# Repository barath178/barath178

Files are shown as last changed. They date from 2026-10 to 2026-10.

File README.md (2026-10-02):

<h1 align="center">Hi, I'm barath178 👋</h1>
<p align="center"><i>Building data-driven tools for agriculture, energy and hardware, from physics models to live dashboards.</i></p>

<p align="center">
  
  
  
  
  
  
</p>

## 🚀 Featured projects

### 🌾 [AeroAgro AI: Panchayat-level weather downscaling](https://github.com/barath178/panchayat-weather-downscaling)
Turns 12–25 km forecasts into ~1.2 km village-level weather using terrain physics (lapse rate, cold-air drainage, orographic lift), then converts it into farmer advisories: spraying, irrigation, pest alerts and PMFBY crop-insurance evidence.
`TypeScript` · [Live site](https://aeroagro.vercel.app)

### 🛢️ [Baghewala CSS + SRP Digital Twin (SIH26120)](https://github.com/barath178/sih26120-digital-twin)
A well-to-surface digital twin for heavy-oil wells that couples Cyclic Steam Stimulation with sucker-rod pumps and searches both settings together. Engineers approve every change. Built on synthetic data, with 92 tests.
`Python` · `React` · `Docker` · [Live demo](https://sih26120-digital-twin-lilac.vercel.app)

### 💪 EMG Gesture Classifier *(private)*
Real-time hand-gesture recognition: BioAmp EXG Pill → Arduino (500 Hz) → filtering → feature extraction → Random Forest / SVM.
`Python` · `Arduino`

## 📊 GitHub stats

<p align="center">
  
  
</p>
<p align="center">
  
</p>

## 📫 Connect
Find my work at [github.com/barath178](https://github.com/barath178).

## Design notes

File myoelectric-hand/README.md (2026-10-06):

# Myoelectric prosthetic hand: complete parts set

This is a rebuild of `original/myoelectric hand buy.step` with every part in place.

The original STEP file held 5 components, and most of them were bare surfaces with no thickness: one finger, the thumb, one side plate, one tab and the wrist puck. The screenshots in `original/` show the full design: 4 sheet-metal fingers (钣金手指), a removable thumb (可拆卸拇指), an emergency-release pin (紧急释放开关), a motor (发动机), two side plates and a base bracket. This folder rebuilds the full design as solid, printable parts. They are built around the exact geometry of the original components.

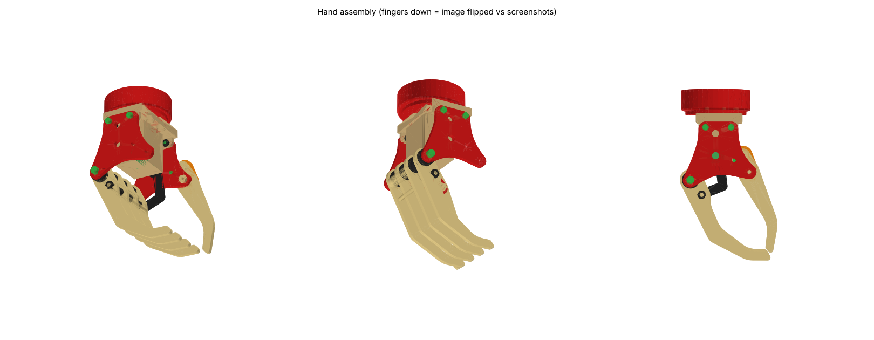
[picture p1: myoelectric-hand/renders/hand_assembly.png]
hand

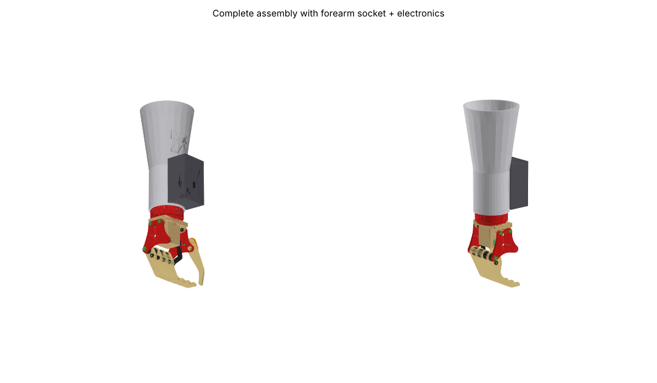
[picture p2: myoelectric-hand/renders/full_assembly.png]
full


## What is where

| Path | Contents |
|---|---|
| `solidworks/` | **For SolidWorks 2025:** 35 part STEP files, an instanced assembly STEP, and a macro that creates .SLDPRT and .SLDASM files. See `solidworks/README.md`. |
| `cad/myoelectric_hand_complete.step` | Full assembly (60 parts, coloured, named). Open it in Fusion, SolidWorks or FreeCAD. |
| `stl_print_ready/` | **Files to slice.** One STL per unique printed part, already laid flat. The quantity is in the file name (`finger_x4.stl` means print 4). |
| `cad/parts_print_step_stl/` | Each printed part as STEP and STL, in assembly position. Use these for editing. |
| `cad/parts_hardware_reference/` | Bought parts (motor, screws, pins, electronics), for fit-checking only. **Do not print.** |
| `cad/print_list.json`, `cad/manifest.json` | Part sizes, volumes and validity flags. |
| `source/` | The CadQuery script that generates everything (`build.py`) and the checks (`check.py`, `motion.py`, `verify_orig.py`). |
| `original/` | Your original STEP file and screenshots, unchanged. |

Units are mm. In assembly coordinates, +Z points toward the forearm, so the fingers hang toward −Z. This is upside down compared with the screenshots. The hand is symmetric about the plane y = −23, which is the wrist axis.

## Which dimensions came from your file, and which are new

**Taken exactly from your STEP file (verified with a 0.000 mm difference):**
- **Finger** (Component75): the full outline, the Ø8 pivot hole at (−17.64, −17.15) and the Ø3 hole at (−9.87, −27.70). The plate is 3.0 mm thick, which the file shows directly through its 0.5 mm edge fillets.
- **Thumb** (Component77): the full outline and both Ø8 holes, at (23.87, −11.50) and (19.97, 0.97).
- **Side plate** (Component78): the full outline and all six holes. These are Ø2.9 at the finger pivot, the thumb pivot and the two tab screws, and Ø5.2 at (0, 0) and (0, 15.6).
- **Tab** (Component76): the outline and its two Ø2.7 holes. It is now part of the base bracket.
- **Wrist puck** (Component79): Ø50 × 14.7 mm with a 1.5 mm fillet, a Ø44 × 2.6 mm spigot, a Ø18.2 bore and a Ø1.5 hole.

**Assumed, because your file has no thickness information for these parts:**
- The side plate, tab and thumb are 3.0 mm thick, the same as the finger.
- The second side plate is a mirror of the first about y = −23. With four fingers spaced 13.33 mm apart, the spacing and the 3 mm side gaps come out equal.
- The thumb sits outside the front plate, between the plate and the orange rocker, as in your screenshots. In the STEP file it sat 10 mm further in, where it would hit finger 1.

**Designed new, to fit the original holes:**
- the base bracket and motor housing
- the pivot tube and spacers
- the coupling-rod spacers
- the crank and the dog-leg drive link
- the thumb rocker
- the forearm socket
- the electronics enclosure and lid

The forearm socket is a generic cone, Ø55 at the wrist and Ø84 at the top, 163 mm long. **It has to be re-shaped to fit the user's own limb before it is worn.**

## Holes added to original parts

Only two holes were added, and none was removed or moved:
- the side plate gets a Ø3.2 hole at (13, −3) for the release pin
- the wrist puck gets M3 pilot holes for the base and socket screws

## Read this before you print

1. **The original Ø2.9 holes are smaller than an M3 screw (3.0 mm).** These are the side-plate finger pivot, the thumb pivot and the tab-screw holes. I kept your size. After printing, drill them to Ø3.2 if you want a clearance fit, or leave them at Ø2.9 so the M3 screw self-taps.
2. On new holes I added 0.2 mm of radial clearance. On a well-calibrated printer, holes still print about 0.1–0.2 mm small. Run a reamer or drill bit through the pivot holes so the fingers swing freely.
3. Suggested settings are PETG or PLA+, 0.2 mm layers, 4 walls and 40 % infill. Print the fingers, side plates, thumb, rocker, crank and link at 100 % infill. The pivot tube is better made from an Ø8 aluminium rod, drilled and tapped M3 at both ends.
4. The STLs in `stl_print_ready/` are already oriented for printing. The base bracket prints with its top face on the bed, and the motor pocket bridges 12 mm. The enclosure prints with its open side down. The socket prints standing up.

## Parts list

**Printed parts** (`stl_print_ready/`):

| File | Qty | Note |
|---|---|---|
| finger_x4 | 4 | original outline |
| side_plate_x2 | 2 | original outline. Print 2 and flip one. |
| thumb_x1 | 1 | original outline |
| thumb_rocker_x1 | 1 | orange rocker; holds the thumb, pivot and release pin |
| base_bracket_with_motor_housing_x1 | 1 | the original tab mirrored on both sides, the base plate and the N20 housing |
| wrist_puck_x1 | 1 | original |
| finger_pivot_tube_x1 | 1 | or an Ø8 aluminium rod |
| pivot_spacer_between_fingers_x3, pivot_spacer_front_x1, pivot_spacer_back_x1 | 5 | |
| rod_spacer_x3 | 3 | |
| crank_arm_x1, drive_link_x1 | 1 each | |
| forearm_socket_x1 | 1 | adapt to the user |
| electronics_enclosure_x1, enclosure_lid_x1 | 1 each | |

**Hardware to buy:**

| Item | Qty | Where it goes |
|---|---|---|
| N20 gear motor, 6 V, about 50 rpm (1:298), Ø3 D-shaft × 10 mm | 1 | motor housing, coaxial with the plate hole at (0, 0) |
| M1.6 × 4 screws | 2 | motor face |
| M3 threaded rod, 52 mm | 1 | finger coupling rod, through the Ø3 hole in every finger |
| M3 nuts | 3 | 2 on the coupling rod, 1 on the thumb pivot |
| M3 × 8 socket-head screws | 6 | 2 hold the pivot tube to the plates, 4 hold the base to the puck |
| M3 × 10 socket-head screws | 3 | socket to puck |
| M3 × 14 screw | 1 | thumb pivot |
| M2.5 × 8 screws and nuts | 4 + 4 | tab to side plates |
| M2.5 × 8 screws | 4 | enclosure lid |
| Ø3 steel pin, cut to 3.6 mm | 1 | crank pin |
| Ø3 × 12 pull pin with head | 1 | emergency release (紧急释放开关) |
| Ø8 × 6 pin with a Ø10 head | 1 | thumb to rocker |
| MyoWare 2.0 EMG sensor and electrodes | 1 | pocket inside the socket |
| Arduino Nano, DRV8833 motor driver | 1 each | enclosure |
| 2S LiPo battery, about 50 × 30 × 10 mm, with a switch | 1 | enclosure. Limit the motor PWM to 80 % or less, because the N20 is rated 6 V. |

## How the hand moves

- **Fingers:** all four fingers turn on the Ø8 pivot tube. The M3 coupling rod and spacers lock them together.
- **Drive:** the N20 motor turns a 5 mm crank. A 34.4 mm dog-leg link joins the crank to the coupling rod at finger 1.
- **Range of motion:** one crank turn takes the fingers from your STEP pose (closed, tips touching the thumb) to 91° open and back.
- **Grip lock:** in the closed pose the crank is at dead-centre, so the grip holds without motor power.
- **Thumb:** the thumb is passive. It is pinned to the rocker, and the rocker pivots on the front plate. Pull the release pin and the thumb swings free.

## Checks run (all scripts in `source/`)

- All 60 parts are valid single solids, and all printed STLs are watertight.
- No parts overlap. The only overlaps are screws biting into their pilot holes, which is intended.
- **Motion check:** the drive was turned through a full crank revolution in 10° steps, moving the fingers, coupling rod, link and crank each time. Nothing collided at any step.
- Every original outline and hole was compared with your STEP file: the difference is 0.000 mm.

## Not tested

- Nothing has been printed. Check the fit of the first finger, side plate and pivot tube before printing the full set.
- The forearm socket is a placeholder shape. It needs fitting to the user's limb.
- Grip force depends on which N20 gear ratio you buy. A 1:298 ratio gives roughly 10–15 N at the fingertip.
- The EMG firmware isn't included.

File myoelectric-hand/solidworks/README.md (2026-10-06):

# SolidWorks 2025 package

SolidWorks .SLDPRT and .SLDASM files can only be written by SolidWorks itself. This folder has everything needed to create them on your PC. Choose **one** of the two methods below. Both give you native part files and an assembly file.

| File | What it is |
|---|---|
| `parts/*.step` | 35 part files, one per unique part (mm, AP214, with colours). Printed parts have plain names; bought parts start with `HW`. |
| `Myoelectric Hand Assembly.step` | The full assembly: 60 components that reference those 35 parts. The 4 fingers are one part used 4 times. |
| `instances.csv` | Position and orientation of each of the 60 components. The macro reads it. |
| `BuildSolidWorksAssembly.bas` | SolidWorks VBA macro for method B. |

## Method A: open the assembly STEP (no macro)

1. In SolidWorks 2025, go to **File → Open** and set the file type to *STEP AP203/214/242 (\*.step;\*.stp)*. Click **Options…** and make sure *Import multiple bodies as parts* is selected, so the file opens as an assembly.
2. Open `Myoelectric Hand Assembly.step`. If you're asked whether to run Import Diagnostics, answer **No**.
3. Go to **File → Save As → Assembly (\*.sldasm)**. When asked about the components, choose **Save all as external files** (or *Save internally* if you prefer a single file). This gives you `Myoelectric Hand Assembly.SLDASM` and 35 `.SLDPRT` files.

## Method B: run the macro (one .SLDPRT per STEP, plus an assembly with every component fixed in place)

1. Go to **Tools → Macro → New…** and save an empty macro, for example `hand.swp`.
2. In the VBA editor that opens, choose **File → Import File…** and select `BuildSolidWorksAssembly.bas`. Then run **Main** (F5).
3. When the folder picker appears, select **this `solidworks` folder**.
4. The macro converts the 35 STEP files into `native_sldworks\*.SLDPRT`. It then builds `native_sldworks\Myoelectric Hand Assembly.SLDASM`, placing all 60 components and fixing each one.

## Notes

- All parts share one coordinate system, and each part sits in its assembly position. That's why every component in the assembly has a zero offset, or a simple translation for repeated parts. The parts line up without any mates.
- Holes, outlines and thicknesses are exactly the same as in `../cad/`. I checked: after reading `Myoelectric Hand Assembly.step` back, all 60 instances match the source parts vertex for vertex (`../source/verify_sw_assembly.py`).
- The imported parts are "dumb" solids with no feature history. You can still add features, cut holes or add mates, and edit faces with *Move Face* or *Delete Face*.
- I couldn't run SolidWorks while preparing this package, so neither method has been tested in SolidWorks itself. Method A uses only standard STEP import, so it's the safer first try. If the macro reports an error, send me the message.

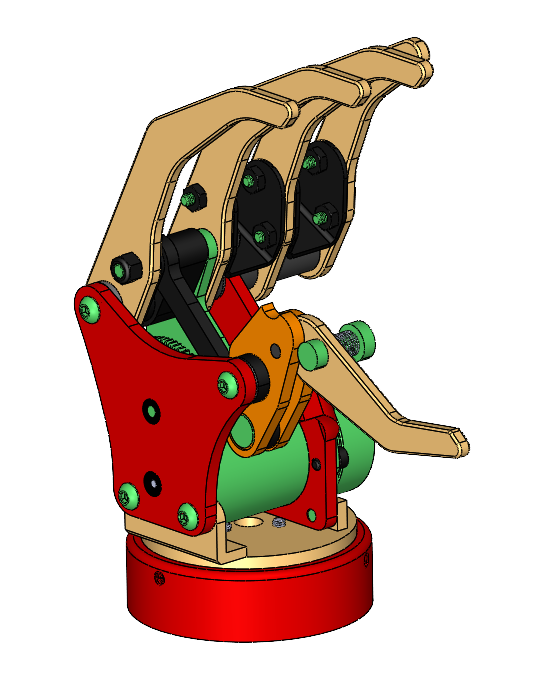
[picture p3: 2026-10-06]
myoelectric-hand/original/Screenshot 2024-10-07 215536.png

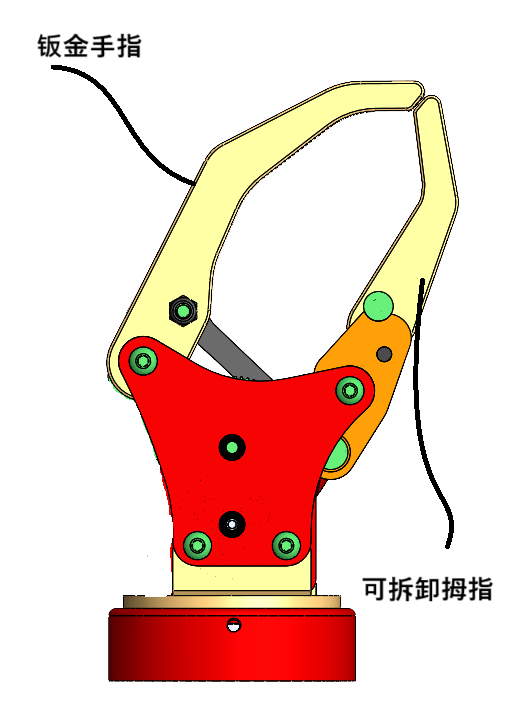
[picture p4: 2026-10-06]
myoelectric-hand/original/Screenshot 2024-10-07 214907.png

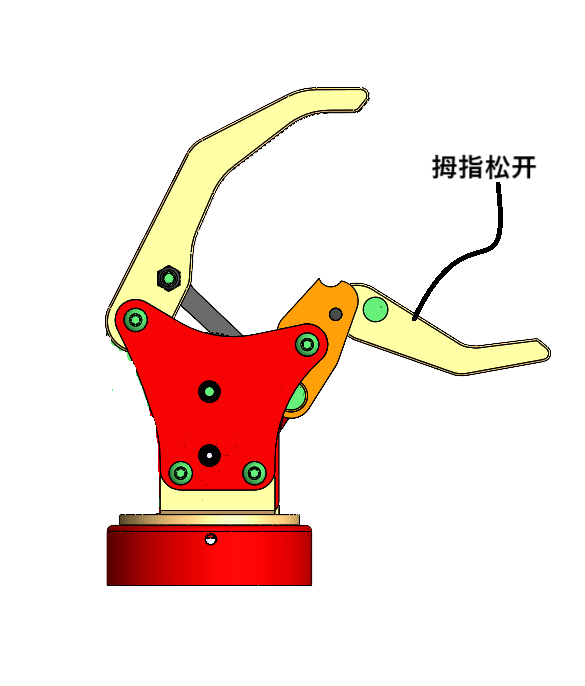
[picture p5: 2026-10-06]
myoelectric-hand/original/Screenshot 2024-10-07 215440.png

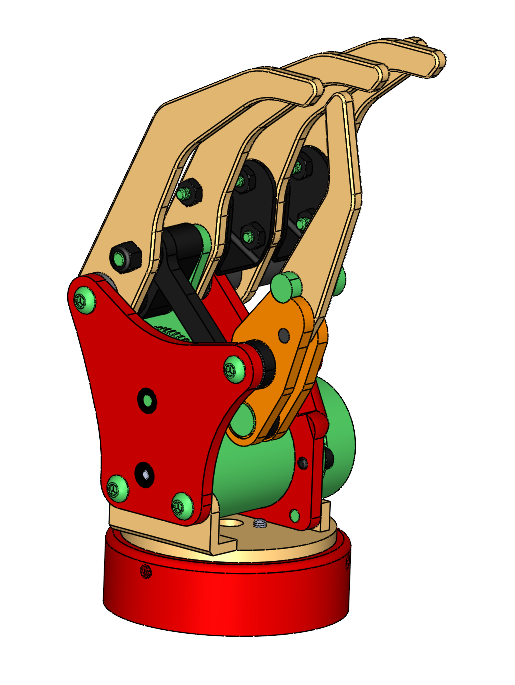
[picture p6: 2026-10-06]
myoelectric-hand/original/Screenshot 2024-10-07 215104.png

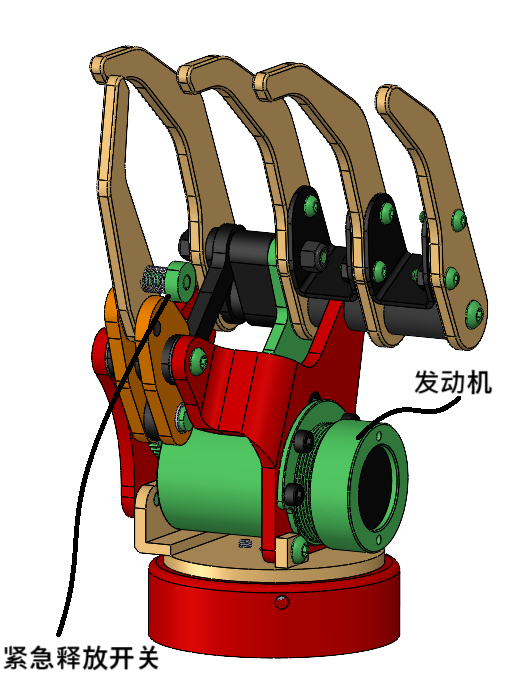
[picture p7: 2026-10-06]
myoelectric-hand/original/Screenshot 2024-10-07 215019.png

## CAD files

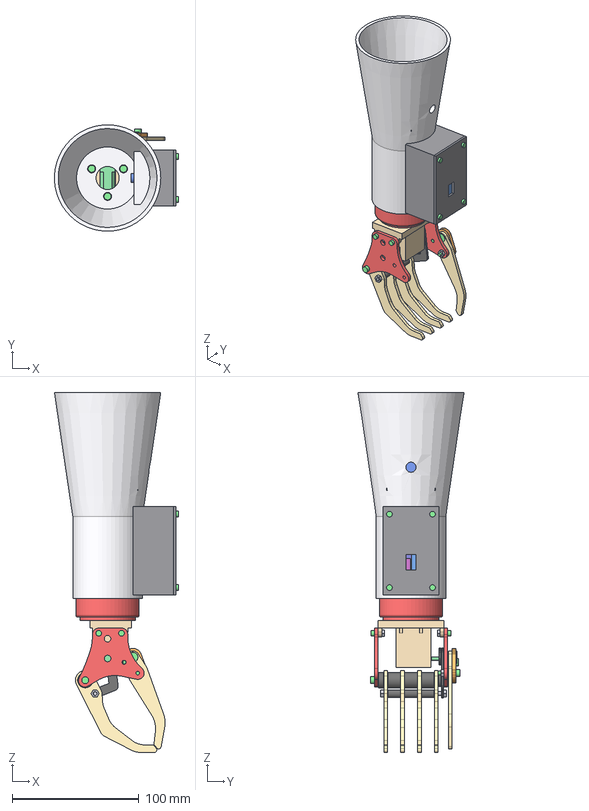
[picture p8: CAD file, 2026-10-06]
myoelectric-hand/cad/myoelectric_hand_complete.step
97.9 x 84.0 x 284.2 mm
side_plate_front
side_plate_back
finger_1
finger_2
finger_3
finger_4
thumb
thumb_rocker
n20_gearmotor_6V_ref
base_bracket_with_motor_housing
wrist_puck
finger_pivot_tube
pivot_spacer_1
pivot_spacer_2
pivot_spacer_3
pivot_spacer_front
pivot_spacer_back
finger_coupling_rod_M3_threaded_x52
rod_spacer_1
rod_spacer_2
rod_spacer_3
nut_M3_rod_front
nut_M3_rod_back
crank_arm
drive_link
crank_pin_D3x4
screw_M3x8_pivot_front
screw_M3x8_pivot_back
screw_M3x14_thumb_pivot
nut_M3_thumb_pivot
thumb_pin_D8x6
release_pin_D3x12
screw_M2.5x8_tab_front_1
screw_M2.5x8_tab_back_1
nut_M2.5_tab_front_1
nut_M2.5_tab_back_1
screw_M2.5x8_tab_front_2
screw_M2.5x8_tab_back_2
nut_M2.5_tab_front_2
nut_M2.5_tab_back_2
screw_M3x8_base_to_puck_1
screw_M3x8_base_to_puck_2
screw_M3x8_base_to_puck_3
screw_M3x8_base_to_puck_4
screw_M1.6x4_motor_1
screw_M1.6x4_motor_2
forearm_socket
emg_sensor_myoware2_ref
electronics_enclosure
enclosure_lid
screw_M3x10_socket_1
screw_M3x10_socket_2
screw_M3x10_socket_3
screw_M2.5x8_lid_1
screw_M2.5x8_lid_2
screw_M2.5x8_lid_3
screw_M2.5x8_lid_4
battery_2S_lipo_50x30x10_ref
arduino_nano_ref
motor_driver_drv8833_ref

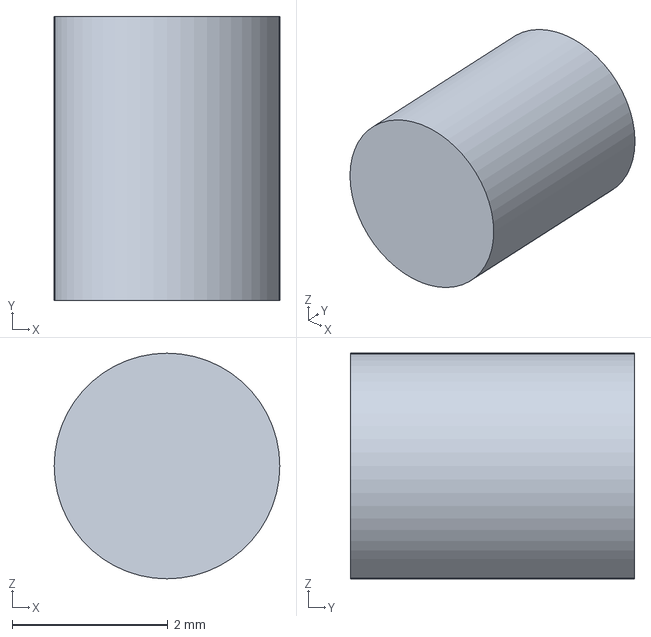
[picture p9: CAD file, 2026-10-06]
myoelectric-hand/cad/parts_hardware_reference/crank_pin_D3x4.step
2.90 x 3.65 x 2.90 mm

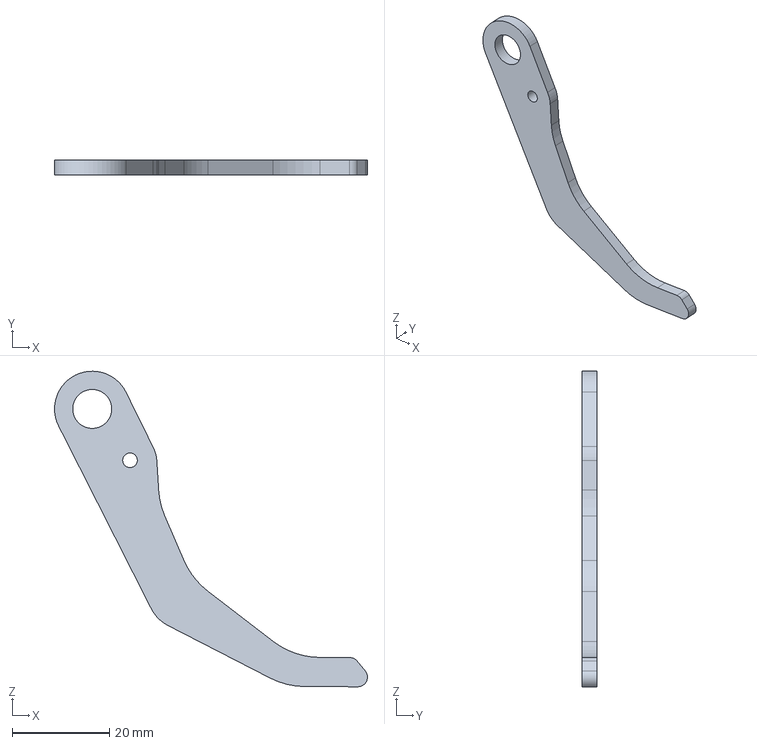
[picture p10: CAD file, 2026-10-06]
myoelectric-hand/cad/parts_print_step_stl/finger_1.step
64.3 x 3.00 x 64.8 mm

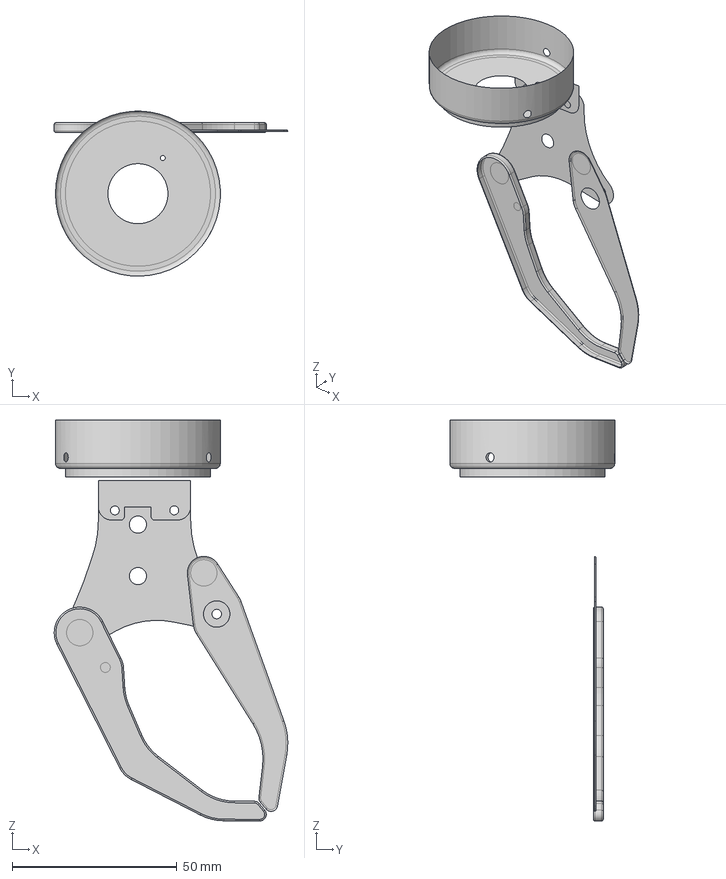
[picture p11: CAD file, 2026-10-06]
myoelectric-hand/original/myoelectric hand buy.step
70.8 x 51.0 x 121.5 mm

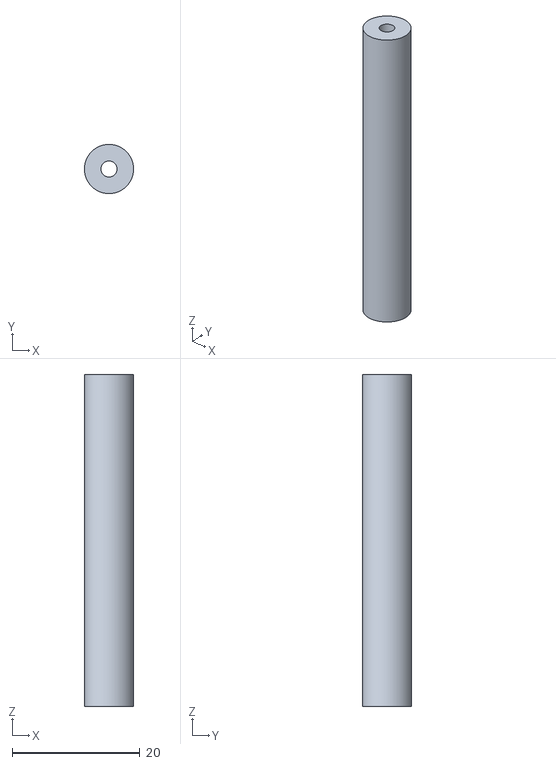
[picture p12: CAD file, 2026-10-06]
myoelectric-hand/stl_print_ready/finger_pivot_tube_x1.stl
7.70 x 7.70 x 52.0

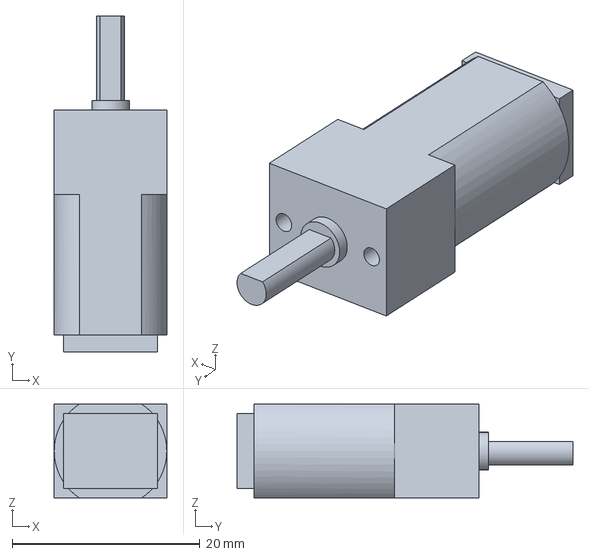
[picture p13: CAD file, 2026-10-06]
myoelectric-hand/cad/parts_hardware_reference/n20_gearmotor_6V_ref.step
12.0 x 35.8 x 10.0 mm

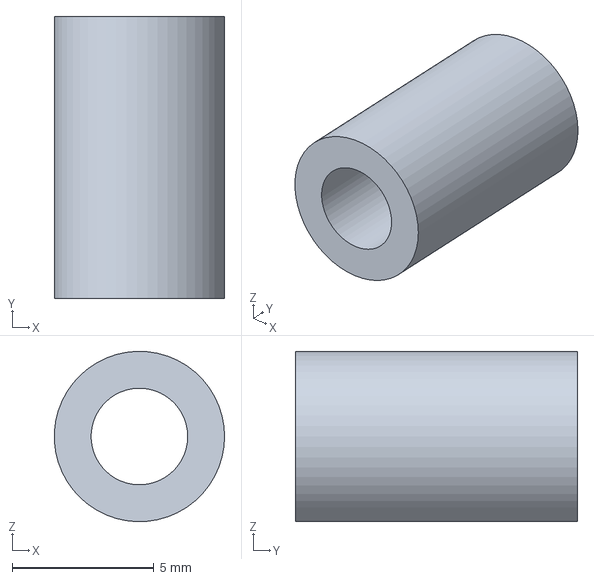
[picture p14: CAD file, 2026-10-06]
myoelectric-hand/cad/parts_print_step_stl/rod_spacer_1.step
5.99 x 9.93 x 6.00 mm

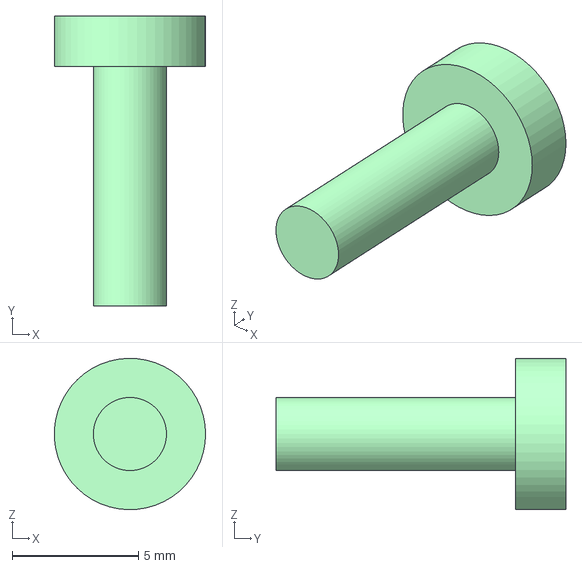
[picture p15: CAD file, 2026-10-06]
myoelectric-hand/solidworks/parts/HW Release Pin D3x12.step
5.99 x 11.5 x 6.00 mm

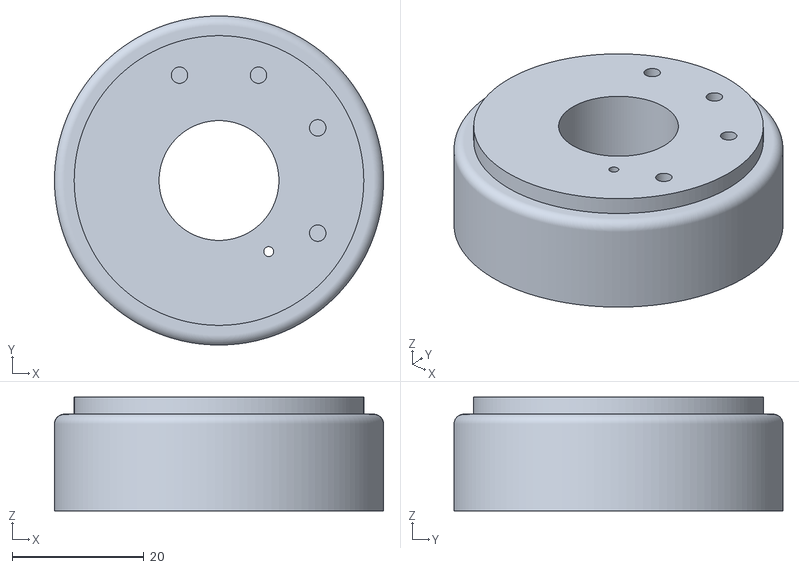
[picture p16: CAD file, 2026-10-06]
myoelectric-hand/stl_print_ready/wrist_puck_x1.stl
50.0 x 50.0 x 17.3

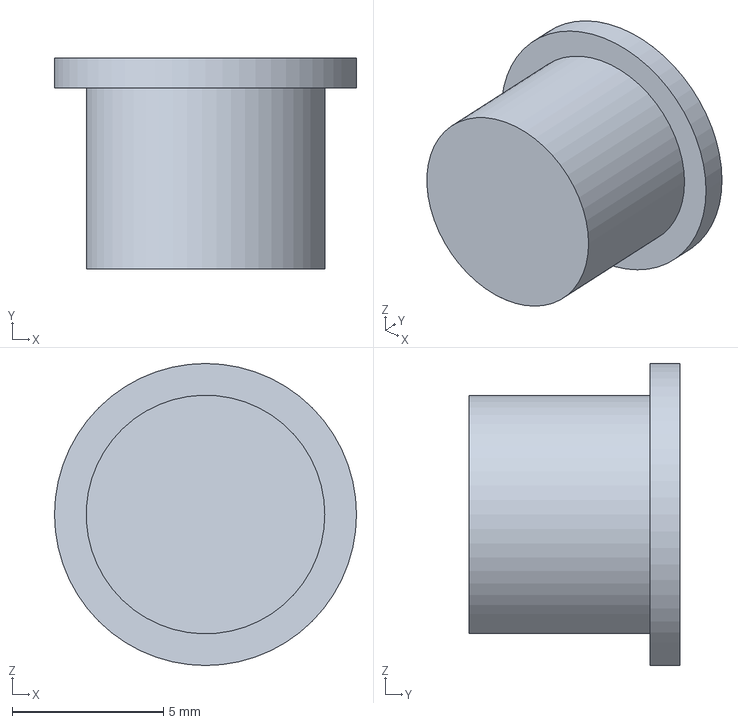
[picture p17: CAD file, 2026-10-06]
myoelectric-hand/cad/parts_hardware_reference/thumb_pin_D8x6.step
10.0 x 7.00 x 10.0 mm

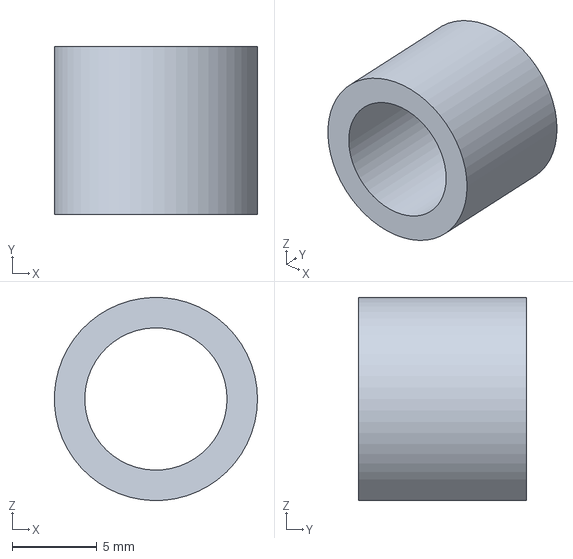
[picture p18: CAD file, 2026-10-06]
myoelectric-hand/cad/parts_print_step_stl/pivot_spacer_1.step
12.0 x 9.93 x 12.0 mm

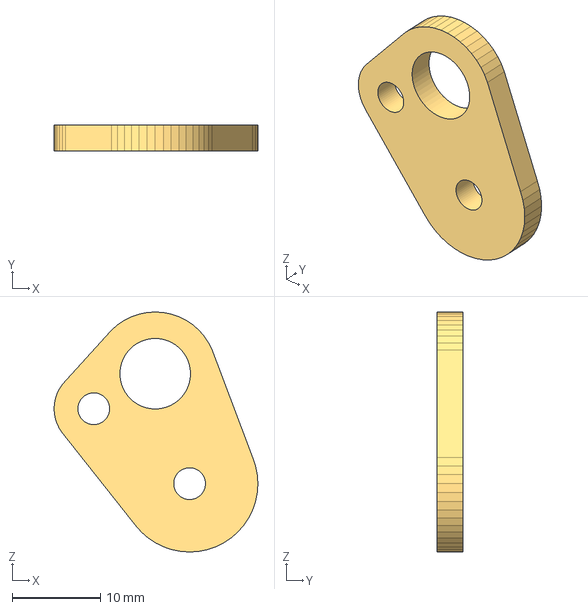
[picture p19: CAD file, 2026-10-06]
myoelectric-hand/solidworks/parts/Thumb Rocker.step
23.1 x 3.00 x 27.2 mm

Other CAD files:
myoelectric-hand/solidworks/Myoelectric Hand Assembly.step
myoelectric-hand/solidworks/parts/HW Pin D3x3.6.step
myoelectric-hand/solidworks/parts/Rod Spacer.step
myoelectric-hand/stl_print_ready/finger_x4.stl
myoelectric-hand/cad/parts_print_step_stl/finger_4.step
myoelectric-hand/stl_print_ready/pivot_spacer_between_fingers_x3.stl
myoelectric-hand/cad/parts_hardware_reference/arduino_nano_ref.step
myoelectric-hand/cad/parts_hardware_reference/battery_2S_lipo_50x30x10_ref.step
myoelectric-hand/cad/parts_hardware_reference/emg_sensor_myoware2_ref.step
myoelectric-hand/cad/parts_hardware_reference/finger_coupling_rod_M3_threaded_x52.step
myoelectric-hand/cad/parts_hardware_reference/motor_driver_drv8833_ref.step
myoelectric-hand/cad/parts_hardware_reference/nut_M2.5_tab_back_1.step
myoelectric-hand/cad/parts_hardware_reference/nut_M2.5_tab_back_2.step
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

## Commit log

2026-10-06 Add complete myoelectric hand parts set rebuilt from the partial STEP
    The original STEP held only 5 components (mostly surfaces). Rebuild all
    parts as printable solids around the exact original outlines and holes:
    4 fingers, both side plates, thumb + rocker, base bracket with N20 motor
    housing, pivot/coupling hardware, crank + dog-leg link, wrist puck,
    forearm socket and electronics enclosure. Includes print-ready STLs,
    full assembly STEP, hardware reference models, BOM and the generator
    and verification scripts (validity, interference, full-stroke motion).
    Claude-Session: https://claude.ai/code/session_01TUAYvzubComnYtdxwcDUYF
    [arduino_nano_ref.step, base_bracket_with_motor_housing.step, base_bracket_with_motor_housing.stl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]
2026-10-06 Add SolidWorks 2025 package: per-part STEP files, instanced assembly, macro
    35 unique part STEP files (identical parts merged, verified by exact
    vertex match), an instanced assembly STEP referencing them (60
    components), instances.csv with each placement, and a VBA macro that
    converts the parts to SLDPRT and builds the SLDASM.
    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
    [Base Bracket with Motor Housing.step, Crank Arm.step, Drive Link.step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]
